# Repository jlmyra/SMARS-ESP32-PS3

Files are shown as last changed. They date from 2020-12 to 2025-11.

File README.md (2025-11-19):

 
# SMARS-ESP32-PS3
SMARS bot with ESP32 using PS3 controller

## 🆕 Latest Updates (2025-11-19)

**Major code improvements added!** See [IMPROVEMENTS.md](IMPROVEMENTS.md) for full details.

### New Features:
- ✅ **Safety:** Fail-safe motor stop, watchdog timer, emergency stop button (PS button)
- ✅ **Control:** Smooth motor acceleration, exponential steering curves, configurable dead zones
- ✅ **Modes:** Speed limiting (50%/75%/100% via L1), Tank turn mode (R1)
- ✅ **Quality:** Complete code refactor, conditional debug output, real-time telemetry
- ✅ **Performance:** Optimized PWM frequency (20kHz), improved loop responsiveness

### Quick Start Guide:
1. **Configure:** Edit `settings.h` in the ESP32_SMARS_PS3-3-GOLD-With_BAT-2 folder
   - Set your PS3 controller MAC address
   - Adjust motor control parameters if needed (defaults work well)
   - Configure battery voltage divider resistor values
2. **Upload:** Upload the improved code to your ESP32
3. **Connect:** Pair your PS3 controller (see setup instructions below)
4. **Drive:**
   - Left Stick Y-axis: Forward/Reverse
   - Right Stick X-axis: Left/Right Turn
   - **L1 Button:** Cycle speed limit (start with 50% for testing!)
   - **R1 Button:** Toggle tank turn mode (pivot in place)
   - **PS Button:** Emergency stop

### Configuration File (settings.h):
All robot parameters are now in a separate `settings.h` file for easy customization:
- Motor control tuning (acceleration, steering sensitivity)
- Safety parameters (watchdog timeout, dead zones)
- Speed limiting modes
- Battery monitoring thresholds
- Pin assignments
- PS3 MAC address

See `settings.example.h` for a template or [IMPROVEMENTS.md](IMPROVEMENTS.md) for detailed configuration guide.

---

This is an adaptation of Kevin McAleer's (https://www.smarsfan.com/) SMARS project. In this version I have lengthened the chassis by one track segment length so that 2 - 18650 batteries fit in the bottom of the chassis just above the motors. Instead of an Arduino microcontroller an MH-ET ESP32 microcontroller is used. I chose this one for its compact size as well as the built in bluetooth and wifi eliminating the need for additional hardware. The ESP32 - PS3 Controller communication is via bluetooth. Jeffrey van Pernis has created an excellent library for PS3 code (See-https://github.com/jvpernis/esp32-ps3). It is available on Github or through the Arduino IDE.
If you are familiar with Arduino evolving to ESP32 should be fairly easy. The Arduino IDE works well with the ESP32 with a few modifications. I have posted links below for further information. The most challenging step in this was setting the PS3 controller MAC address. The biggest difference you will find in coding the ESP32 is that the digitalWrite() and analogWrite() functions are replaced by ledcWrite(). There are a few more items that need to be setup to get PWM working. There is a good resource for this here - https://randomnerdtutorials.com/esp32-pwm-arduino-ide/
I have included the code in a 'tabbed' format and files (.stl's) for the modified chassis, mounting plate, dome and a wiring diagram. 

### ESP32 - PS3 Controller Parts:
- MH-ET ESP32 Microcontroller - https://acrobotic.com/collections/esp8266/products/acr-00024 ($6.95)
- HiLetGo L9110S DC Motor Controller - https://tinyurl.com/y57pky5p ($1.50)
- PS3 Controller - Amazon : https://tinyurl.com/y3ootahd ($19.90)
- 2.54mm pitch Screw Terminal Blocks - https://tinyurl.com/yxtv7g5w (~$15 for 50)
- 42.3K resistors
- 101.3K resistor
- 0.1uf capacitor
- 5V, 3A BEC/UBEC (battery elimination circuit) - https://tinyurl.com/y3t4wqus (~$4.00) or https://tinyurl.com/y2z84n8p
- 2 Cell 18650 battery holder
- Wire

### Software Implementation:
- Set-up ESP32 in Arduino IDE (for help see: https://randomnerdtutorials.com/installing-the-esp32-board-in-arduino-ide-mac-and-linux-instructions/)
- Install PS3 Library in Arduino IDE https://github.com/jvpernis/esp32-ps3 (for help see: https://techtutorialsx.com/2020/02/16/esp32-connecting-a-ps3-controller/). Follow the instructions at either link for setting or determining the MAC address of your PS3 controller. 
- Description: The sketch is presented in a 'tabbed' format for ease of editing. The files are:
   - **ESP32_SMARS_PS3-3-GOLD.ino** contains the variables, setup, and loop. Enter your PS3 MAC Address on Line 70 in void Setup().
   - **Battery_Check.ino** is a function that samples the battery voltage on an ADC setup on GPIO32. It is commented out in the main Loop and does not need to be used.
   - **Connection.ino** is a function that looks for the bluetooth connection between the ESP32 and the PS3 controller.
   - **onEvent.ino** is a function that listens for changes occuring on the PS3 controller and converts them to motor actions for FORWARD, REVERSE, LEFT-RIGHT turns.
   - **Citations.ino** includes the license, useful links and recognition to those that contributed to this by sharing their wisdom and code.
These five files need to be downloaded into a folder for the Arduino IDE to access.
- I use cheap knockoff PS3 controllers. I have not tried an authentic PS3 controller but hopefully they provide more accuracy than the knockoffs. One of my knockoffs does not zero out the joysticks in the 'neutral' position and the range is not balanced up - down and left - right. JVPernis provides sketches in his library that makes is easy to see the controller performance on the serial monitor.

### Circuit Diagram

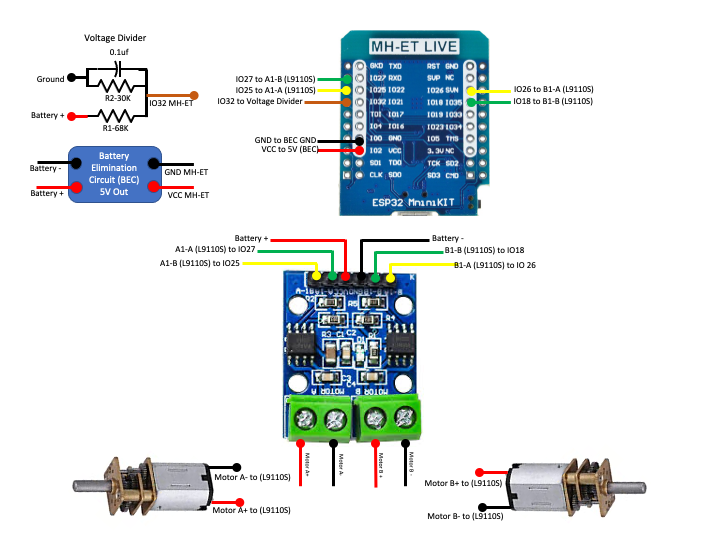
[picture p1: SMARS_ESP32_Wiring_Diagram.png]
pic one


### Wiring
   

 - I used 2.54mm pitch screw terminal blocks for making circuit board connections instead of soldering wires directly to the circuit boards. This makes it easy to fix wiring issues (mistakes!). It also makes it easy to reuse the boards in other applications.
 - I offer suggestions for 2 different BEC's necessary to reduce the battery voltage from ~8V to 5V for the ESP32. The second one in the parts list is much smaller making it preferable over the other. Any device that will reduce the battery voltage to 5V can be used.
 - The L9110s motor controller was selected as it was cheap and easy to get. Any dual channel controller can be used. The L9110S comes with a 6 pin terminal block on one end. I have had mixed success removing the pins and soldering in 2.54 pitch screw terminals. I now solder the screw terminals to the pins instead. It's functional but not very neat.

### Chassis
- I have included .stl's for the modified (elongated) chassis, ESP32/L9110S mounting plate and dome. 
- The elongated chassis is based on a four motor design. With this I use the adjustable wheel modification found here - https://www.thingiverse.com/thing:3164589
- The printed dome fits better if printed 'right-side-up' with supports. When printed upside down - the flat side on the print bed it will likely have a loose fit. 

### ESP32 Battery Charge Monitor
(see - https://randomnerdtutorials.com/esp32-adc-analog-read-arduino-ide/#:~:text=The%20ESP32%20DEVKIT%20V1%20DOIT,use%20the%20analogRead()%20function)

Battery monitor circuits for the ESP32 are a challenge since the ADC is nonlinear particularly at the ends of its range. Between 2.6V and 3.3V the ADC will output similar values. The same happens at the low end of the range as well. In monitoring a pair of 18650's a small voltage range is needed to determine the state of the battery charge. LIPO's should be recharged when they reach 80% of their full charge voltage or 80% of 8.4V = 6.7V. This narrow range makes it easy
to use a linear portion of the ADC curve. The ESP32 ADC resolution is adjustable. It can be a value between 9 (0 – 511) and 12 bits (0 – 4095). Default is 
12-bit resolution. 

The sketch uses the pre-calibrated reference voltage in determining a corrected voltage on the ADC. see - https://deepbluembedded.com/esp32-adc-tutorial-read-analog-voltage-arduino/ for a full explanation.

A voltage divider is necessary to reduce 8.4V battery voltage to something the ADC can use. Given the nonlinearity of the ADC I chose resistors R1-101.3K and R2-43.2K to give ~2.5V output at 8.4V. A 0.1uf capacitor is connected across Vout and ground to clean up the signal.  Enter the values of your resistors in line 40 and 41 of ESP32_SMARS_PS3-3-GOLD-With_BAT-2. Just insure that they yield ~2.5V with the voltage divider calculator.
(see - https://www.mischianti.org/2019/06/15/voltage-divider-calculator-and-application/) 

To smooth out the ADC reading the ADC is read every 2ms, 500 times with computing a new average every second. This may be overkill but it's what I chose to do.
The ESP32 communicates the charge status of the battery by lighting the 'Player' LEDs on the side panel of the PS3 controller. 4 LEDs = 75-100%, 3 LEDs = 50-74%, 2 LEDs = 25-49%, 1 LED < 24%. At 0% or ~6.7V the vibration motors are turned on in the PS3 controller alerting the operator to recharge the batteries.

### Final Thoughts
I am grateful to Kevin McAleer for sharing the SMARS project with us. Thanks!

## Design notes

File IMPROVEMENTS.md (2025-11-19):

# SMARS ESP32 PS3 Controller - Code Improvements

## Overview
This document details the comprehensive improvements made to the SMARS ESP32 PS3 robot control code. All improvements focus on safety, control quality, and user experience.

---

## 🛡️ Safety Features (Critical)

### 1. Fail-Safe Motor Stop on Disconnect
**Location:** `ESP32_SMARS_PS3-3-GOLD-With_BAT-2.ino:255-270`
- **What it does:** Immediately stops all motors when PS3 controller disconnects
- **Why it matters:** Prevents runaway robot if controller loses connection
- **Implementation:** Calls `emergencyStopMotors()` in main loop when `!Ps3.isConnected()`

### 2. Event Timeout Watchdog
**Location:** `ESP32_SMARS_PS3-3-GOLD-With_BAT-2.ino:273-281`
- **What it does:** Stops motors if no controller events received for 500ms
- **Why it matters:** Protects against frozen controller that stays "connected" but stops sending data
- **Configuration:** Adjust `EVENT_TIMEOUT_MS` constant (default: 500ms)
- **Implementation:** Tracks `lastEventTime` and stops motors if timeout exceeded

### 3. Emergency Stop Button
**Location:** `onEvent.ino:34-50`
- **What it does:** PS button toggles emergency stop mode
- **Why it matters:** Provides immediate panic button to stop all movement
- **Usage:** Press PS button to stop, press again to resume
- **Implementation:** Sets `emergencyStop` flag which blocks all motor commands

---

## ⚡ Motor Control Improvements

### 4. Motor Speed Ramping/Acceleration
**Location:** `ESP32_SMARS_PS3-3-GOLD-With_BAT-2.ino:127-157`
- **What it does:** Smoothly accelerates/decelerates motors instead of instant changes
- **Benefits:**
  - Reduces mechanical stress on drivetrain
  - Prevents wheel slip and improves traction
  - Smoother, more controllable movement
- **Configuration:** Adjust `RAMP_RATE` constant (0.1 = slower, 0.3 = faster, default: 0.15)
- **Implementation:** Uses `targetSpeed` and `currentSpeed` with exponential smoothing

### 5. Exponential Steering Curves
**Location:** `ESP32_SMARS_PS3-3-GOLD-With_BAT-2.ino:120-125`, `onEvent.ino:161-167`
- **What it does:** Applies exponential curve to steering input for better fine control
- **Benefits:**
  - More precise control at low speeds
  - More aggressive turning at high stick deflection
  - Natural, intuitive feel
- **Configuration:** Adjust `STEERING_EXPO` constant (1.0 = linear, 2.0 = squared, 3.0 = cubic)
- **Math:** `output = sign(input) * |input|^EXPO`

### 6. Configurable Dead Zones
**Location:** `ESP32_SMARS_PS3-3-GOLD-With_BAT-2.ino:15`, `onEvent.ino:135-141`
- **What it does:** Ignores small joystick movements within deadzone threshold
- **Benefits:**
  - Compensates for controller drift
  - Prevents unwanted movement from worn joysticks
  - Easy to adjust for different controllers
- **Configuration:** Adjust `JOYSTICK_DEADZONE` constant (default: 5, was hardcoded at 3)

---

## 🎮 New Features

### 7. Speed Limiting Modes
**Location:** `onEvent.ino:59-69`
- **What it does:** Three speed limit modes: 50%, 75%, 100%
- **Benefits:**
  - Better control for beginners
  - Safer in tight spaces
  - Preserves battery when full speed not needed
- **Usage:** Press L1 button to cycle through modes
- **Current mode:** Displayed via telemetry and status messages

### 8. Tank Turn Mode (Pivot in Place)
**Location:** `onEvent.ino:71-80`, `onEvent.ino:93-125`
- **What it does:** Enables in-place rotation by driving tracks in opposite directions
- **Benefits:**
  - Turn in confined spaces
  - Precise positioning
  - More maneuverable
- **Usage:** Press R1 button to toggle tank turn mode
- **Controls:** When active and left stick centered, right stick controls rotation

### 9. Improved Control Scheme
**New differential steering algorithm:**
- **Location:** `onEvent.ino:127-182`
- **Benefits:**
  - Cleaner code structure
  - More predictable behavior
  - Easier to maintain
- **Algorithm:**
  - Calculates base speed from throttle
  - Applies exponential curve to steering
  - Differentially adjusts left/right tracks

---

## 📊 Code Quality & Performance

### 10. Refactored Event Handler
**Location:** `onEvent.ino` (complete rewrite)
- **Before:** 136 lines of nested if-else statements
- **After:** Clean, structured code with clear sections
- **Benefits:**
  - Much easier to understand and modify
  - Reduced code duplication
  - Better separation of concerns

### 11. Conditional Debug Printing
**Location:** All files - wrapped Serial prints with `if (DEBUG_SERIAL)`
- **What it does:** Debug output can be disabled to improve performance
- **Configuration:** Set `DEBUG_SERIAL false` to disable (default: true)
- **Benefits:**
  - Faster response time when debug not needed
  - Cleaner serial output in production
  - Easy to enable for troubleshooting

### 12. Helper Functions
**Location:** `ESP32_SMARS_PS3-3-GOLD-With_BAT-2.ino:96-194`
- **Functions added:**
  - `emergencyStopMotors()` - Centralized motor stop logic
  - `applySteeringCurve()` - Exponential steering calculation
  - `rampMotorSpeeds()` - Smooth motor acceleration
  - `printTelemetry()` - Diagnostic output
- **Benefits:** Code reuse, better organization, easier testing

---

## 📈 Diagnostics & Telemetry

### 13. Real-time Telemetry
**Location:** `ESP32_SMARS_PS3-3-GOLD-With_BAT-2.ino:159-194`
- **What it displays:**
  - Current speed limit mode (50%/75%/100%)
  - Tank turn mode status (ON/OFF)
  - Current motor speeds (left/right)
  - Target motor speeds (left/right)
  - Time since last controller event
  - Main loop frequency (Hz)
- **Configuration:** Displays every 1 second when `DEBUG_SERIAL` enabled
- **Benefits:** Real-time insight into robot behavior for tuning and debugging

### 14. Enhanced Connection Feedback
**Location:** `Connection.ino:4-30`
- **What it does:** Displays control scheme when controller connects
- **Benefits:**
  - User knows controls without reading documentation
  - Confirms successful connection
  - Shows current capabilities

---

## 🔧 Configuration File (settings.h)

All configurable parameters are now in a separate **`settings.h`** file for easy customization!

### Key Advantages:
- ✅ All settings in one place
- ✅ Well-organized and documented
- ✅ Easy to share configurations
- ✅ Can use `settings.example.h` as a template
- ✅ Professional code organization

### Main Configuration Categories:

**Debug & Diagnostics:**
```cpp
#define DEBUG_SERIAL true        // Enable/disable debug output
#define TELEMETRY_INTERVAL_MS 1000  // Telemetry reporting rate
```

**Controller Input:**
```cpp
#define JOYSTICK_DEADZONE 5      // Joystick deadzone threshold
```

**Safety:**
```cpp
#define EVENT_TIMEOUT_MS 500     // Watchdog timeout in milliseconds
```

**Motor Control Tuning:**
```cpp
#define RAMP_RATE 0.15           // Motor acceleration rate (0.05-1.0)
#define STEERING_EXPO 2.0        // Steering curve exponent (1.0-3.0)
#define PWM_FREQUENCY 20000      // PWM frequency in Hz
```

**Speed Limiting:**
```cpp
#define DEFAULT_SPEED_LIMIT_MODE 2  // 0=50%, 1=75%, 2=100%
#define SPEED_LIMIT_MODE_0 0.50     // Customize each mode
#define SPEED_LIMIT_MODE_1 0.75
#define SPEED_LIMIT_MODE_2 1.00
```

**Battery Monitoring:**
```cpp
#define BATTERY_R1 101300        // Voltage divider resistor values
#define BATTERY_R2 42300
#define BATTERY_FULL_VOLTAGE 8.4
#define BATTERY_LOW_VOLTAGE 6.7
```

**Hardware Configuration:**
```cpp
#define PS3_MAC_ADDRESS "b8:27:eb:37:85:b9"  // Your controller MAC
#define MOTOR_LEFT_FWD_PIN 27    // GPIO pin assignments
// ... etc
```

### Tuning Recommendations:
- **RAMP_RATE**: Increase for more responsive acceleration, decrease for smoother
- **STEERING_EXPO**: Increase for more aggressive steering, decrease for more linear
- **JOYSTICK_DEADZONE**: Increase if you have controller drift
- **EVENT_TIMEOUT_MS**: Adjust based on your controller's update rate

### Using settings.h:
1. Copy `settings.example.h` to `settings.h` if needed
2. Edit `settings.h` with your preferences
3. Upload to ESP32
4. Settings take effect immediately

---

## 🎯 Control Summary

### Button Mapping
| Button/Stick | Function |
|---|---|
| Left Stick Y | Forward/Reverse |
| Right Stick X | Left/Right Turn (Normal Mode) |
| Right Stick X | Rotation (Tank Turn Mode) |
| L1 Button | Cycle Speed Limit (50%→75%→100%) |
| R1 Button | Toggle Tank Turn Mode |
| PS Button | Emergency Stop (Toggle) |

---

## ⚠️ Breaking Changes

### Changes from Original Code:
1. **PWM Frequency:** Changed from 30kHz to 20kHz (may reduce motor whine)
2. **Deadzone:** Increased from 3 to 5 (adjustable)
3. **Motor Control:** Complete rewrite - behavior may feel different initially
4. **Acceleration:** Motors now ramp instead of instant response

### Migration Notes:
- Test at 50% speed limit first to get familiar with new behavior
- Adjust `RAMP_RATE` if acceleration feels too slow/fast
- Adjust `STEERING_EXPO` if steering feels too sensitive/insensitive
- Original behavior can be approximated with: `RAMP_RATE=1.0`, `STEERING_EXPO=1.0`

---

## 🧪 Testing Recommendations

Before full operation:
1. ✅ Test emergency stop (PS button) - ensure motors stop immediately
2. ✅ Test disconnect safety - disconnect controller, verify motors stop
3. ✅ Test at 50% speed limit first
4. ✅ Verify all directions (forward, reverse, left, right)
5. ✅ Test tank turn mode
6. ✅ Test speed ramping feels smooth
7. ✅ Verify battery monitoring still works
8. ✅ Check serial output for any errors

---

## 📝 Future Enhancement Ideas

Potential additions (not yet implemented):
- [ ] Configurable motor speed curves per track (for motors with different characteristics)
- [ ] Trim adjustment (if robot drifts to one side)
- [ ] Multiple ramping profiles (sport/comfort/eco)
- [ ] Button to reverse controls (for when robot is facing you)
- [ ] Low battery warning via controller LED
- [ ] Data logging to SD card
- [ ] WiFi telemetry and tuning interface
- [ ] Obstacle detection integration
- [ ] Auto-stop on excessive motor current (stall detection)

---

## 🙏 Credits

Original SMARS project by Kevin McAleer (https://www.smarsfan.com/)
ESP32 PS3 Library by Jeffrey van Pernis (https://github.com/jvpernis/esp32-ps3)

Improvements by: Claude Code (Anthropic)
Date: 2025-11-19

---

## 📄 License

This code maintains the same license as the original SMARS ESP32 PS3 project.

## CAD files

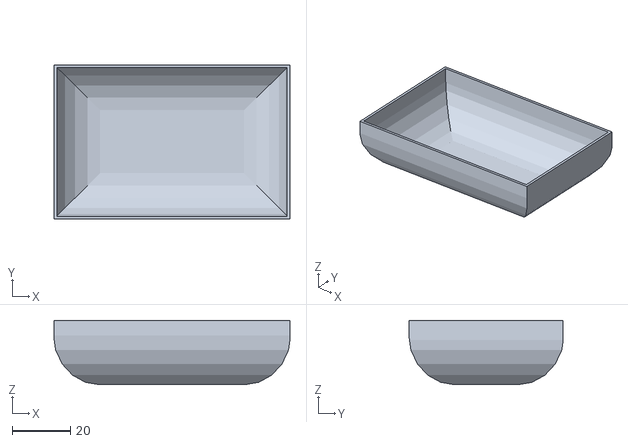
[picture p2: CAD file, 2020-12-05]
SMARS_Dome-4.stl
81.0 x 53.0 x 22.0

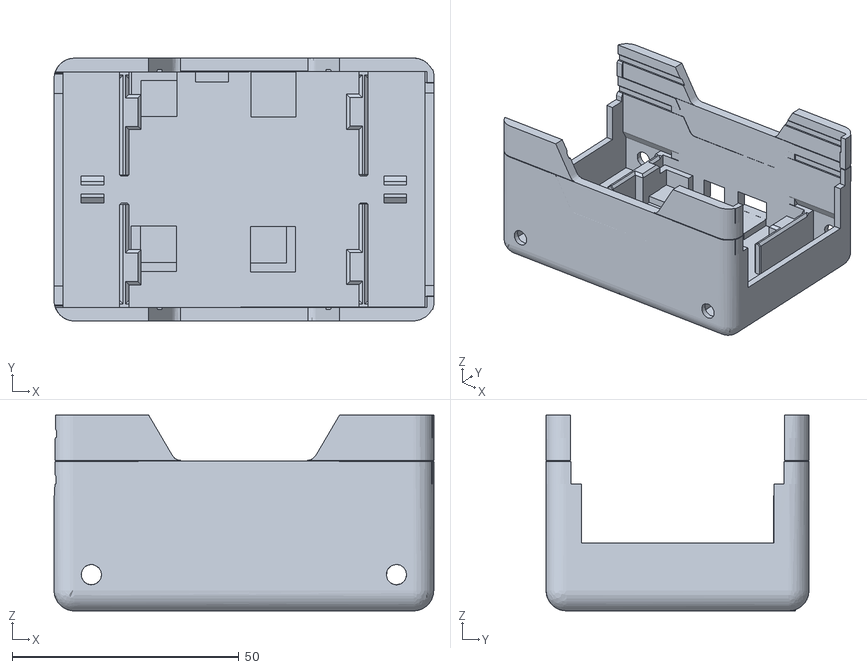
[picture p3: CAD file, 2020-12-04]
SMARS_Elongagated-Final.stl
83.8 x 58.0 x 43.2

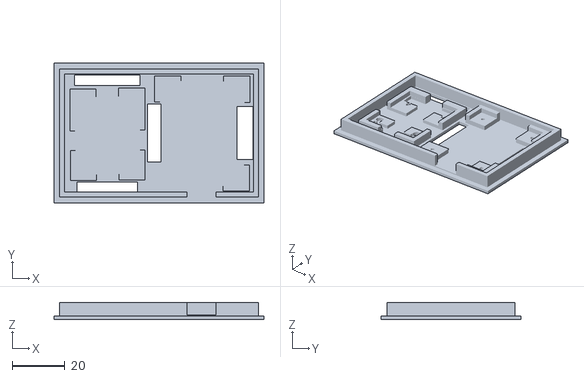
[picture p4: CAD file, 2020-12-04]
SMARS_Mounting_Plate-5.stl
80.0 x 53.2 x 6.59

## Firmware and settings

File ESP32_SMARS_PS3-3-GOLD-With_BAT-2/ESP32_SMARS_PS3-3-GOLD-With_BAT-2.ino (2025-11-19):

//SMARS Tracked Vehicle Controller PS3 on MH ET Live ESP32 Bluetooth
//Enhanced with Safety Features, Motor Ramping, and Improved Control

//Uses L9110 2-CHANNEL MOTOR DRIVER. Spec sheet-https://tinyurl.com/y88pgaka

//**********Libraries**********

#include <Ps3Controller.h>
#include "esp_adc_cal.h"
#include "settings.h"  // User configuration file

//********************MOTORS***************************
uint32_t freq = PWM_FREQUENCY; //PWM Frequency from settings.h
uint8_t resolution = PWM_RESOLUTION; //PWM resolution from settings.h

// PWM Channel assignments from settings.h
uint8_t motorA1AChannel = MOTOR_LEFT_REV_CHANNEL;  // Left Motor Reverse
uint8_t motorA1BChannel = MOTOR_LEFT_FWD_CHANNEL;  // Left Motor Forward
uint8_t motorB1AChannel = MOTOR_RIGHT_REV_CHANNEL; // Right Motor Reverse
uint8_t motorB1BChannel = MOTOR_RIGHT_FWD_CHANNEL; // Right Motor Forward

// GPIO Pin assignments from settings.h
int motorA1ApwmPin = MOTOR_LEFT_REV_PIN;   // Left Motor Reverse Pin
int motorA1BpwmPin = MOTOR_LEFT_FWD_PIN;   // Left Motor Forward Pin
int motorB1ApwmPin = MOTOR_RIGHT_REV_PIN;  // Right Motor Reverse Pin
int motorB1BpwmPin = MOTOR_RIGHT_FWD_PIN;  // Right Motor Forward Pin

// Motor speed variables
int motorSpeed = 0;
int motorSpeedADJ = 0;

// Motor ramping variables (for smooth acceleration)
float currentSpeedLeft = 0.0;
float currentSpeedRight = 0.0;
float targetSpeedLeft = 0.0;
float targetSpeedRight = 0.0;

//********************MOTORS***************************

//*************Joystick Variables*********
int leftJoystickPos = 0;
int rightJoystickPos = 0;
int leftRight = 0;

//*************Joystick Variables*********

//***************Safety & Control Features*************
unsigned long lastEventTime = 0;  // Watchdog timer for event timeout
bool emergencyStop = false;       // Emergency stop flag
bool tankTurnMode = false;        // Tank turn mode (pivot in place)

// Speed limit modes from settings.h
int speedLimitMode = DEFAULT_SPEED_LIMIT_MODE;
float speedLimitFactors[3] = {SPEED_LIMIT_MODE_0, SPEED_LIMIT_MODE_1, SPEED_LIMIT_MODE_2};

//***************Safety & Control Features*************

//***************Telemetry & Diagnostics****************
unsigned long lastTelemetryTime = 0;
unsigned long telemetryInterval = TELEMETRY_INTERVAL_MS; // From settings.h
unsigned long loopCounter = 0;
unsigned long lastLoopTime = 0;

//***************Telemetry & Diagnostics****************

//****************Battery Voltage Alarm******************************/
int batStatusLED = 0; //Variable to hold rover battery status on controller
int R1 = BATTERY_R1; //Voltage divider R1 from settings.h
int R2 = BATTERY_R2; //Voltage Divider R2 from settings.h

float adcRead = 0;
float batteryVoltage = 0; //voltage at ADC pin (after voltage divider)
float batteryVoltageSum = 0;
float batteryVoltageAvg = 0; //averaged voltage at ADC pin
float batteryVoltageCorr = 0; //actual battery voltage (after divider calculation & correction)

unsigned long analogReadCounter = 0;

const int batPin = BATTERY_ADC_PIN; //Battery ADC pin from settings.h
unsigned long previousMillis = 0; //for timer reading battery ADC
unsigned long interval = BATTERY_READ_INTERVAL_MS; // Battery read interval from settings.h

int rumbleCounter = 0;

//****************END Battery Voltage Alarm******************************/

//*****************************************************************************
//****************************HELPER FUNCTIONS*********************************
//*****************************************************************************

// Emergency stop - immediately stop all motors and reset speeds
void emergencyStopMotors() {
  ledcWrite(motorA1AChannel, 0);
  ledcWrite(motorA1BChannel, 0);
  ledcWrite(motorB1AChannel, 0);
  ledcWrite(motorB1BChannel, 0);

  // Reset all speed variables
  currentSpeedLeft = 0.0;
  currentSpeedRight = 0.0;
  targetSpeedLeft = 0.0;
  targetSpeedRight = 0.0;
  motorSpeed = 0;
  motorSpeedADJ = 0;

  if (DEBUG_SERIAL) {
    Serial.println("*** EMERGENCY STOP ACTIVATED ***");
  }
}

// Apply exponential curve to steering for better fine control
float applySteeringCurve(float input) {
  // input is -1.0 to 1.0
  float sign = (input >= 0) ? 1.0 : -1.0;
  return pow(fabs(input), STEERING_EXPO) * sign;
}

// Ramp motor speeds smoothly to target
void rampMotorSpeeds() {
  // Smoothly ramp current speeds toward target speeds
  currentSpeedLeft += (targetSpeedLeft - currentSpeedLeft) * RAMP_RATE;
  currentSpeedRight += (targetSpeedRight - currentSpeedRight) * RAMP_RATE;

  // Apply ramped speeds (constrain to 0-255)
  int leftSpeed = constrain((int)fabs(currentSpeedLeft), 0, 255);
  int rightSpeed = constrain((int)fabs(currentSpeedRight), 0, 255);

  // Determine direction and apply to motors
  if (currentSpeedLeft >= 0) {
    // Left track forward
    ledcWrite(motorA1AChannel, 0);
    ledcWrite(motorA1BChannel, leftSpeed);
  } else {
    // Left track reverse
    ledcWrite(motorA1AChannel, leftSpeed);
    ledcWrite(motorA1BChannel, 0);
  }

  if (currentSpeedRight >= 0) {
    // Right track forward
    ledcWrite(motorB1AChannel, 0);
    ledcWrite(motorB1BChannel, rightSpeed);
  } else {
    // Right track reverse
    ledcWrite(motorB1AChannel, rightSpeed);
    ledcWrite(motorB1BChannel, 0);
  }
}

// Print telemetry data
void printTelemetry() {
  if (!DEBUG_SERIAL) return;

  unsigned long currentTime = millis();
  if (currentTime - lastTelemetryTime >= telemetryInterval) {
    Serial.println("===== TELEMETRY =====");
    Serial.print("Speed Limit Mode: ");
    Serial.print(speedLimitMode);
    Serial.print(" (");
    Serial.print(speedLimitFactors[speedLimitMode] * 100);
    Serial.println("%)");
    Serial.print("Tank Turn Mode: ");
    Serial.println(tankTurnMode ? "ON" : "OFF");
    Serial.print("Current Speed L/R: ");
    Serial.print(currentSpeedLeft);
    Serial.print(" / ");
    Serial.println(currentSpeedRight);
    Serial.print("Target Speed L/R: ");
    Serial.print(targetSpeedLeft);
    Serial.print(" / ");
    Serial.println(targetSpeedRight);
    Serial.print("Last Event: ");
    Serial.print(currentTime - lastEventTime);
    Serial.println("ms ago");
    Serial.print("Loop Frequency: ");
    if (lastLoopTime > 0) {
      Serial.print(1000.0 / (currentTime - lastLoopTime));
      Serial.println(" Hz");
    }
    Serial.println("====================");

    lastTelemetryTime = currentTime;
    lastLoopTime = currentTime;
  }
}

//*****************************************************************************
//*************************END HELPER FUNCTIONS********************************
//*****************************************************************************

//*****************************************************************************
//********************************VOID SETUP***********************************
//*****************************************************************************

void setup() {

Serial.begin(SERIAL_BAUD_RATE); // Serial Port Speed from settings.h

  if (!Ps3.begin(PS3_MAC_ADDRESS)) { //MAC address from settings.h
    Serial.println("Initialization failed.");
    return;
  }
  Serial.println();
  Serial.println();
  Serial.println("*****************************************************");
  Serial.println("Initialization finished. Ready to pair PS3 controller");
  Serial.println("*****************************************************");
  Serial.println();
  Serial.println();
 
  Ps3.attach(onEvent);
  Ps3.attachOnConnect(onConnection);

//Battery Meter Setup (only if enabled in settings.h)
  #if ENABLE_BATTERY_MONITORING
    pinMode(batPin, INPUT);
  #endif

  pinMode(motorA1ApwmPin,OUTPUT); //Set  PIN to OUTPUT
  pinMode(motorA1BpwmPin,OUTPUT); //Set  PIN to OUTPUT
  pinMode(motorB1ApwmPin,OUTPUT); //Set  PIN to OUTPUT
  pinMode(motorB1BpwmPin,OUTPUT); //Set  PIN to OUTPUT

  ledcSetup(motorA1AChannel, freq, resolution);
  ledcAttachPin(motorA1ApwmPin, motorA1AChannel); 

  ledcSetup(motorA1BChannel, freq, resolution);
  ledcAttachPin(motorA1BpwmPin, motorA1BChannel);

  ledcSetup(motorB1AChannel, freq, resolution);
  ledcAttachPin(motorB1ApwmPin, motorB1AChannel);

  ledcSetup(motorB1BChannel, freq, resolution);
  ledcAttachPin(motorB1BpwmPin, motorB1BChannel);
}
//**********************************************************************
//*************************END VOID SETUP*******************************
//**********************************************************************

//**********************************************************************
//***************************VOID LOOP**********************************
//**********************************************************************

void loop() {

  loopCounter++;

  // SAFETY: Check if PS3 controller is disconnected
  if(!Ps3.isConnected()) {
    if (DEBUG_SERIAL) {
      Serial.println();
      Serial.println();
      Serial.println("***************************");
      Serial.println("PS3 Controller Disconnected");
      Serial.println("***************************");
      Serial.println();
      Serial.println();
    }

    // CRITICAL: Stop all motors immediately on disconnect
    emergencyStopMotors();

    return;
  }

  // SAFETY: Event timeout watchdog - stop motors if no events received for EVENT_TIMEOUT_MS
  unsigned long currentTime = millis();
  if (currentTime - lastEventTime > EVENT_TIMEOUT_MS && !emergencyStop) {
    if (DEBUG_SERIAL && (targetSpeedLeft != 0 || targetSpeedRight != 0)) {
      Serial.println("*** WATCHDOG TIMEOUT - No events received, stopping motors ***");
    }
    targetSpeedLeft = 0;
    targetSpeedRight = 0;
  }

  // Apply motor speed ramping for smooth acceleration/deceleration
  rampMotorSpeeds();

  // Read and compute battery voltage (only if enabled in settings.h)
  #if ENABLE_BATTERY_MONITORING
    computeBatteryVoltage();
  #endif

  // Print telemetry (rate-limited)
  printTelemetry();
}

//**************************************************************************
//*************************END VOID LOOP************************************
//**************************************************************************

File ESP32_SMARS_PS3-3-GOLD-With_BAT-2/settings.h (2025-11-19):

#ifndef SETTINGS_H
#define SETTINGS_H

//*****************************************************************************
//*********************  SMARS ESP32 PS3 CONFIGURATION  ***********************
//*****************************************************************************
//
// This file contains all user-configurable parameters for the SMARS robot.
// Adjust these values to tune the robot's behavior to your preferences.
//
//*****************************************************************************

//=============================================================================
// DEBUG & DIAGNOSTICS
//=============================================================================
// Set to false to disable serial debug output for better performance
#define DEBUG_SERIAL true

// Telemetry reporting interval in milliseconds (0 to disable)
#define TELEMETRY_INTERVAL_MS 1000

//=============================================================================
// CONTROLLER INPUT SETTINGS
//=============================================================================
// Joystick deadzone - increase if controller drifts (range: 0-20, default: 5)
#define JOYSTICK_DEADZONE 5

//=============================================================================
// SAFETY FEATURES
//=============================================================================
// Watchdog timeout - stops motors if no events received (milliseconds)
// Recommended: 300-1000ms depending on controller update rate
#define EVENT_TIMEOUT_MS 500

//=============================================================================
// MOTOR CONTROL TUNING
//=============================================================================
// Motor acceleration/deceleration rate
// Lower = smoother but slower response (range: 0.05-1.0, default: 0.15)
// 0.05 = very smooth/slow, 0.15 = balanced, 0.30 = aggressive, 1.0 = instant
#define RAMP_RATE 0.15

// Steering exponential curve for fine control
// Higher = more sensitive near center (range: 1.0-3.0, default: 2.0)
// 1.0 = linear, 2.0 = squared (balanced), 3.0 = cubic (very sensitive center)
#define STEERING_EXPO 2.0

//=============================================================================
// PWM SETTINGS
//=============================================================================
// PWM frequency in Hz - adjust if motors whine
// 15000-25000 Hz is typical, 20000 Hz recommended
#define PWM_FREQUENCY 20000

// PWM resolution in bits (8 = 0-255, don't change unless you know what you're doing)
#define PWM_RESOLUTION 8

//=============================================================================
// MOTOR PIN ASSIGNMENTS (MH-ET ESP32 + L9110S Motor Driver)
//=============================================================================
#define MOTOR_LEFT_FWD_PIN   25  // GPIO25 - A1B - Left Motor Forward
#define MOTOR_LEFT_REV_PIN   27  // GPIO27 - A1A - Left Motor Reverse
#define MOTOR_RIGHT_FWD_PIN  18  // GPIO18 - B1B - Right Motor Forward
#define MOTOR_RIGHT_REV_PIN  26  // GPIO26 - B1A - Right Motor Reverse

//=============================================================================
// PWM CHANNEL ASSIGNMENTS
//=============================================================================
#define MOTOR_LEFT_FWD_CHANNEL   1  // PWM Channel for left forward
#define MOTOR_LEFT_REV_CHANNEL   0  // PWM Channel for left reverse
#define MOTOR_RIGHT_FWD_CHANNEL  3  // PWM Channel for right forward
#define MOTOR_RIGHT_REV_CHANNEL  2  // PWM Channel for right reverse

//=============================================================================
// SPEED LIMITING
//=============================================================================
// Default speed limit mode on startup (0=50%, 1=75%, 2=100%)
#define DEFAULT_SPEED_LIMIT_MODE 2

// Speed limit percentages for each mode (modify if you want different limits)
#define SPEED_LIMIT_MODE_0 0.50  // 50% - Beginner/tight spaces
#define SPEED_LIMIT_MODE_1 0.75  // 75% - Normal operation
#define SPEED_LIMIT_MODE_2 1.00  // 100% - Full speed

//=============================================================================
// BATTERY MONITORING
//=============================================================================
// Enable/disable battery voltage monitoring
// Set to false if you don't have the voltage divider circuit installed
#define ENABLE_BATTERY_MONITORING false  // Set to true to enable battery monitoring

// Battery voltage divider resistor values (in ohms)
// Original settings from your commented-out defines:
//   #define setR1 101300;
//   #define setR2 42300;
//   #define set_voltageCorrection 0.07;
#define BATTERY_R1 101300  // Resistor R1 (high side)
#define BATTERY_R2 42300   // Resistor R2 (low side)
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

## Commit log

2025-11-19 Major improvements: Safety features, motor control enhancements, and new features
    This commit implements comprehensive improvements to the SMARS ESP32 PS3 controller code,
    focusing on safety, control quality, and user experience.
    Safety Features (Critical):
    - Add fail-safe motor stop on disconnect - prevents runaway robot
    - Implement event timeout watchdog (500ms) - stops motors if controller freezes
    - Add emergency stop button (PS button) - immediate panic stop capability
    - Stop motors automatically when controller connects (safety initialization)
    Motor Control Improvements:
    - Add motor speed ramping/acceleration for smooth movement (reduces mechanical stress)
    - Implement exponential stee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
    [Connection.ino, ESP32_SMARS_PS3-3-GOLD-With_BAT-2.ino, onEvent.ino]
2025-11-19 Add settings.h configuration file for better organization
    Refactor all configuration parameters into a separate settings.h file
    following Arduino best practices. This makes the code more professional
    and easier to customize.
    Changes:
    - Create settings.h with all user-configurable parameters
    - Create settings.example.h as a template
    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
2025-11-19 Add BATTERY_VOLTAGE_CORRECTION constant to settings.h
    Preserve original battery voltage correction parameter from user's
    original settings.h file that had commented-out defines.
    - Add BATTERY_VOLTAGE_CORRECTION constant (0.07V) to settings.h
    - Update Battery_Check.ino to use constant instead of hardcoded 0.07
    - Add reference comments showing original commented-out defines:
    - setR1 101300
    - setR2 42300
    - set_voltageCorrection 0.07
    - Update both settings.h and settings.example.h
    This ensures all battery-related constants are properly exposed in
    the configuration file, and users can see the connection to the
    original parameter naming.
    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
    [Battery_Check.ino, settings.example.h, settings.h]
2025-11-19 Fix battery voltage calculation - reads too low
    CRITICAL FIX: Battery voltage was being calculated incorrectly,
    causing fully charged batteries to show as low (1 LED warning).
    Root Cause:
    - Old method used complex mSlope calculation with double correction
    - Voltage correction was subtracted, then added back after slope multiply
    - This caused incorrect amplification of the error
    - Simplified battery voltage calculation to direct voltage divider formula:
    Battery Voltage = ADC Voltage * (R1 + R2) / R2
    - Removed mSlope and vOutMax variables (no longer needed)
    - Fixed BATTERY_VOLTAGE_CORRECTION application (now simply added)
    - Changed default BATTERY_VOLTAGE_CORRECTION from 0.07 to 0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
    [Battery_Check.ino, Battery_Diagnostics.ino, ESP32_SMARS_PS3-3-GOLD-With_BAT-2.ino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]
2025-11-19 Fix Battery_Diagnostics.ino compilation errors
    Remove references to deleted vOutMax and mSlope variables.
    Calculate expectedVout locally instead.
    This fixes the compilation errors:
    - 'vOutMax' was not declared in this scope
    - 'mSlope' was not declared in this scope
    [Battery_Diagnostics.ino]
2025-11-19 Add ENABLE_BATTERY_MONITORING setting to disable battery monitoring
    Add compile-time option to disable battery voltage monitoring for bots
    that don't have the voltage divider circuit installed.
    - Add ENABLE_BATTERY_MONITORING setting to settings.h (default: false)
    - Wrap computeBatteryVoltage() call with #if ENABLE_BATTERY_MONITORING
    - Wrap pinMode(batPin, INPUT) with conditional compilation
    - Update settings.example.h with the new setting
    - Add clear comments explaining when to enable/disable
    Benefits:
    - Eliminates incorrect voltage readings for bots without the circuit
    - Saves processing time by skipping unnecessary ADC reads
    - Makes it easy to enable when circuit is installed (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
    [ESP32_SMARS_PS3-3-GOLD-With_BAT-2.ino, settings.example.h, settings.h]
2025-11-19 Fix left motor direction - tracks were running opposite directions
    CRITICAL FIX: When moving joystick forward, left track ran backward while
    right track ran forward. Tracks ran in opposite directions.
    - Incorrectly swapped GPIO25 and GPIO27 pin assignments for left motor
    - Original code used GPIO25 (A1B) for forward, GPIO27 (A1A) for reverse
    - New settings.h had them reversed
    Fix:
    - Swap MOTOR_LEFT_FWD_PIN and MOTOR_LEFT_REV_PIN definitions
    - GPIO25 is now correctly defined as forward
    - GPIO27 is now correctly defined as reverse
    - Right motor pins were already correct (no change)
    Updated files:
    - settings.h
    - settings.example.h
    After this fix, both tracks will now run forward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
    [settings.example.h, settings.h]
2025-11-19 Fix inverted steering - stick left now turns left
    CRITICAL FIX: Steering direction was backward. When right stick pushed
    left, bot turned right instead of left.
    - Steering input from right joystick was not inverted
    - PS3 controller gives positive values for stick right, negative for left
    - But the differential steering logic needed opposite polarity
    - Negate steering input: steering = -rightJoystickPos
    - Update tank turn mode to match inverted steering direction
    - Update debug print to show correct turn direction
    Now works correctly:
    - Right stick LEFT → bot turns LEFT ✓
    - Right stick RIGHT → bot turns RIGHT ✓
    - Tank turn mode also fixed to match
    Tested: Both nor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
    [onEvent.ino]
